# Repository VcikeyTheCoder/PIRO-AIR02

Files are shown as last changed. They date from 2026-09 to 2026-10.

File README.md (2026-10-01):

# PIRO-AIR

**A high-flow, load-cell-probing toolhead for printed-gantry printers, built to perform without a big price tag.**

 

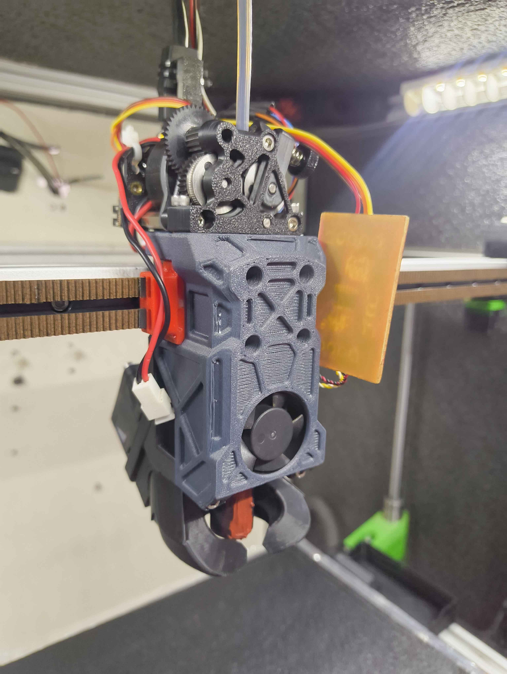
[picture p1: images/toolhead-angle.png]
PIRO-AIR on the printer


PIRO-AIR is a toolhead designed around components that actually make sense together. Printed-gantry machines are usually paired with whatever toolhead is on hand, and that is often where performance gets left behind. This design picks a Sherpa-pattern extruder, a K2 Plus hotend with its load cell, and a 4028 part-cooling fan, then arranges them so the center of mass sits between the linear rail blocks.

https://github.com/user-attachments/assets/fda07650-8147-4dfd-afff-dfcc1e427e6a

**Status: complete and open for beta testing.** There is no assembly guide or BOM yet, so you will work from the CAD for now (see [Assembly](#assembly)). Feedback is welcome, especially from anyone running a similar printed-gantry setup.

---

## Highlights

- **High flow:** the K2 Plus hotend sustains **32 mm³/s** with normal filament, and has run **PC-CF at up to 350 °C for 24+ hours**.
- **Fast, precise probing:** load-cell probing at **5 mm/s** with **1.4 µm** standard deviation (down from 4.5 µm at 2 mm/s). See [Probing](#probing).
- **Clean input shaper results:** a single dominant resonance peak on both axes, MZV recommended, under 1 % residual vibration. See [Input shaper](#input-shaper).
- **Cooling ducts designed for a 4028 fan:** low back pressure and a direct flow path. In testing you do not need more than about 50–60 % fan speed, even for a speed benchy.
- **Balanced mass:** the extruder motor sits slightly behind the hotend and mounts directly on the linear rail block, keeping a direct-drive filament path.
- **No supports needed** for any printed part.
- **Estimated total cost: about USD 100–150.**

---

## Gallery

| | |
|---|---|
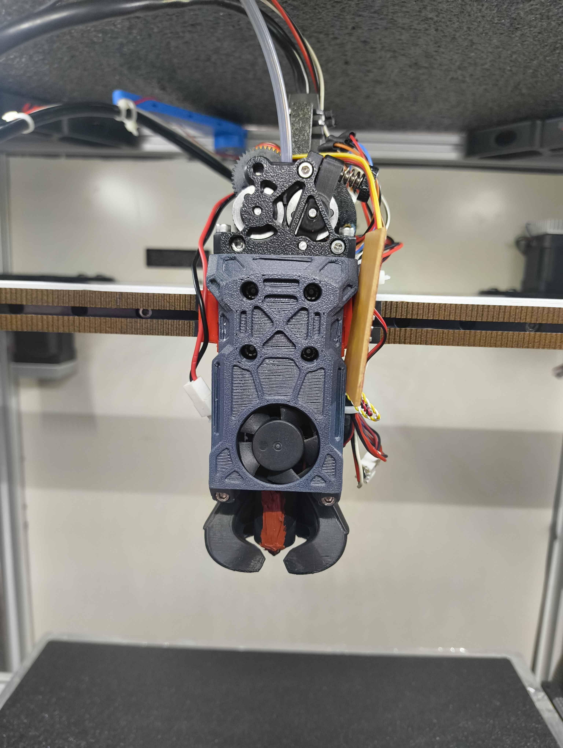
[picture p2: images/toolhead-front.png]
Front view
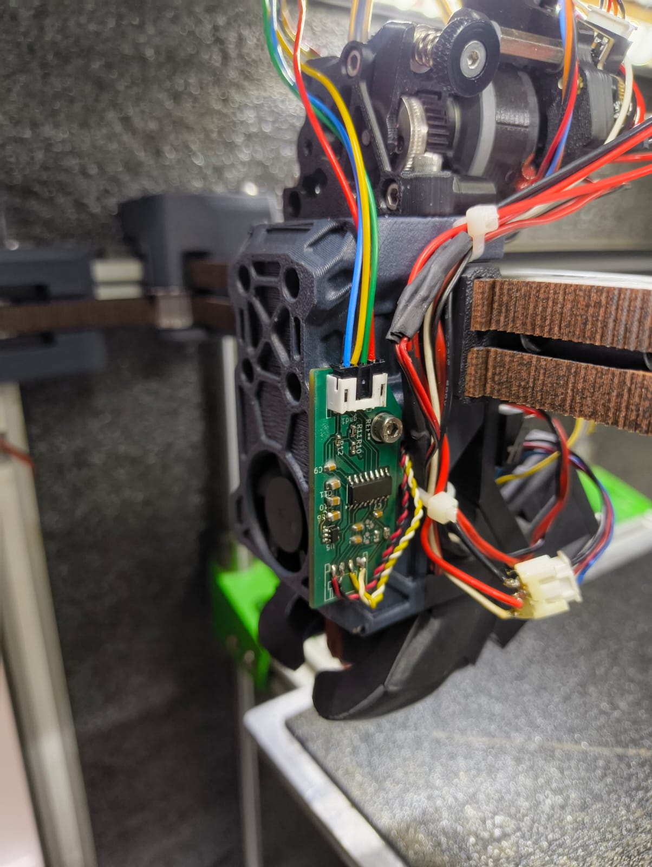
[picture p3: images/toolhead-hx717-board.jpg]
Load cell amplifier board mounted
|  |  |
| Front view | HX717 load cell amplifier board mounted on the side |
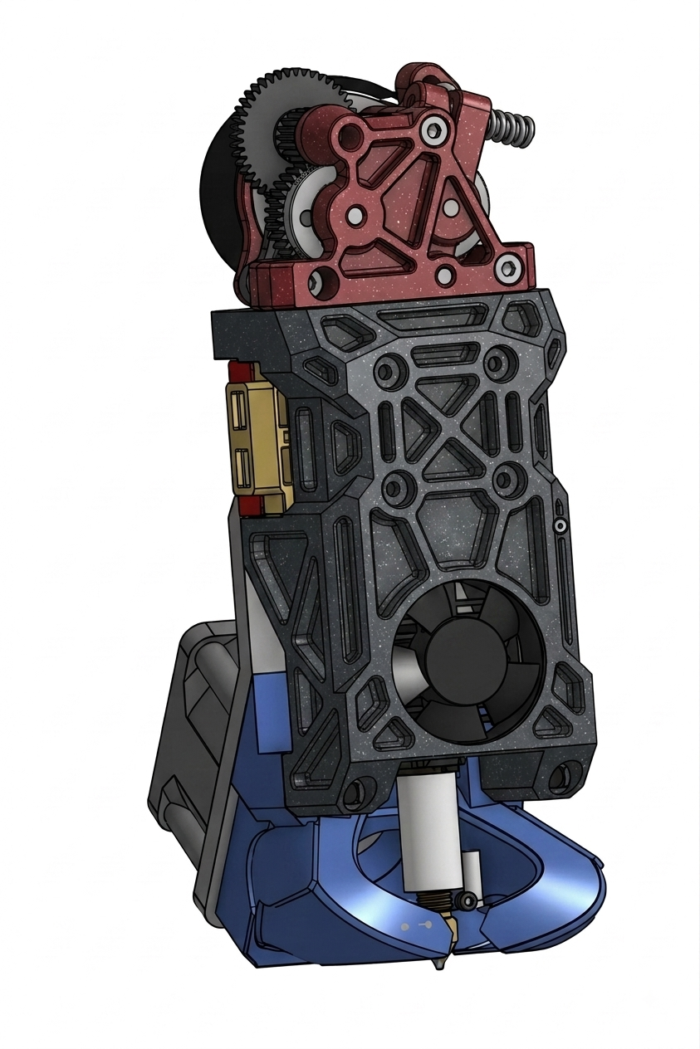
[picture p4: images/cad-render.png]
CAD render
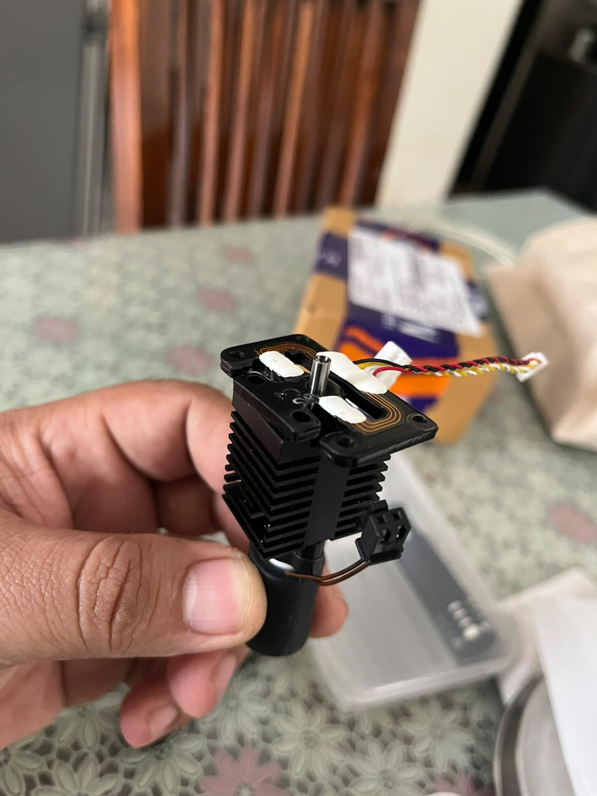
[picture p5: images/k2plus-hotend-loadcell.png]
K2 Plus hotend and load cell
|  |  |
| CAD render | K2 Plus hotend and load cell |
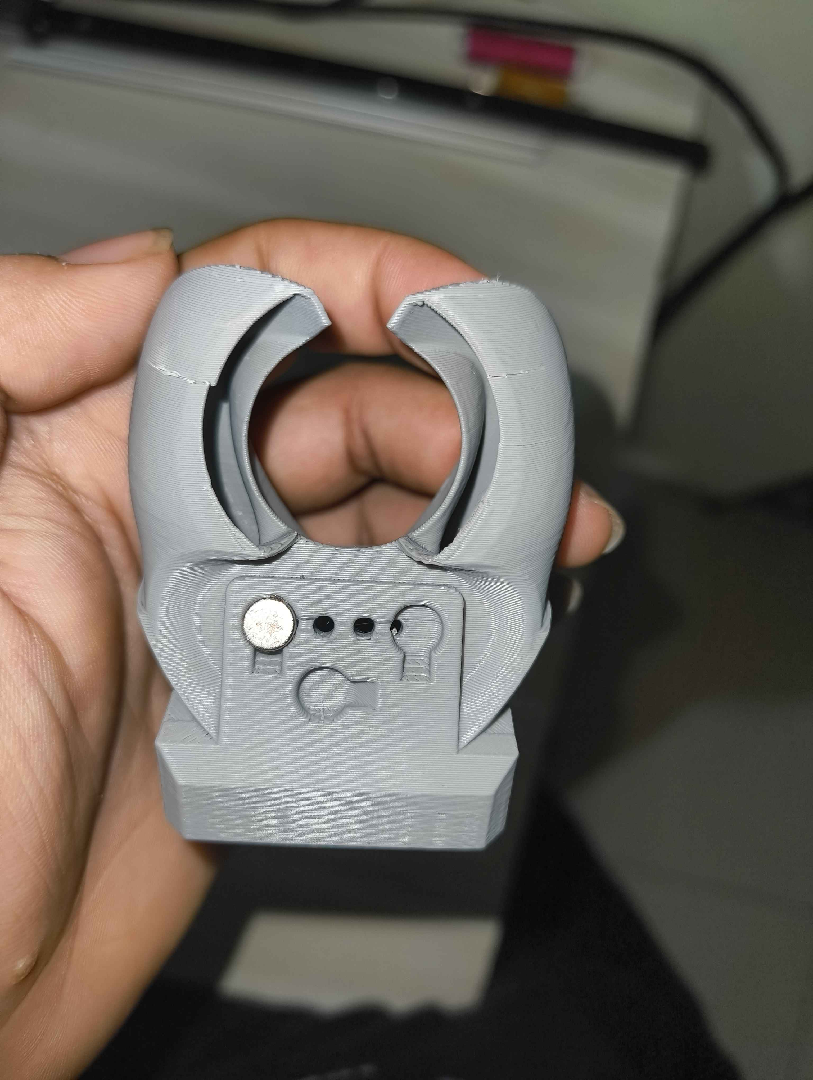
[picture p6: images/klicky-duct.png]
Klicky duct
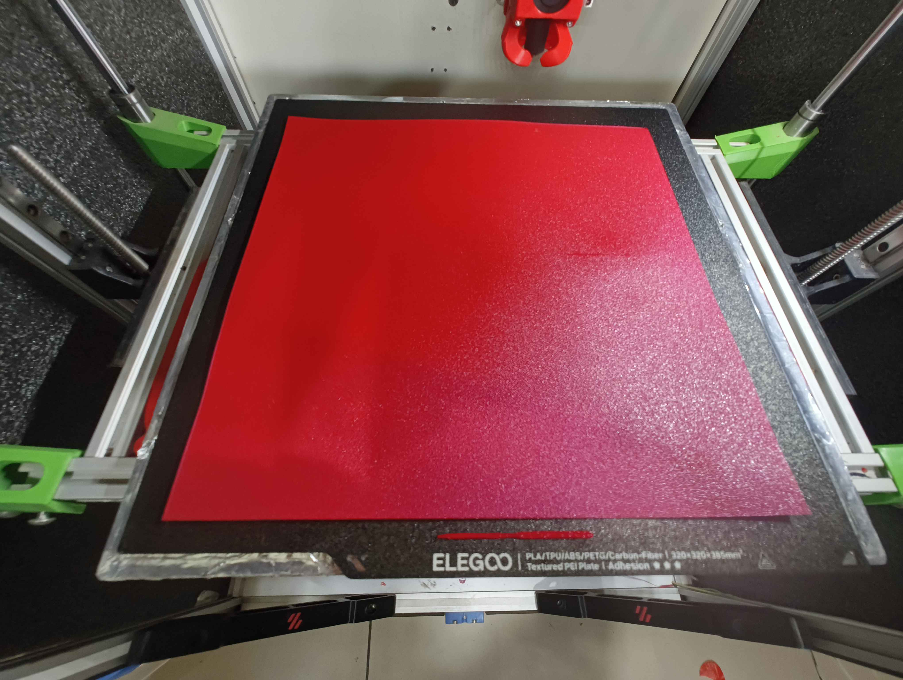
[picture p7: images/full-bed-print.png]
Full-bed print
|  |  |
| Klicky probe duct variant (magnet mount) | Full-bed print |

<!-- TODO: confirm whether the tan board in toolhead-front.png / toolhead-angle.png is an earlier iteration of the amplifier board mount, and label photos by iteration if they differ. -->

---

## Supported hardware

| Component | Supported now | Planned |
|---|---|---|
| **Hotend** | Creality K2 Plus (original recommended; OEM versions also work and cut cost) | |
| **Extruder** | Any Sherpa Mini-pattern extruder. Main target and COM-optimized: [ProtoXtruder](https://github.com/nhchiu/VoronMods/tree/main/Extruders/ProtoXtruder) | |
| **Probe** | K2 Plus load cell, Klicky probe | Eddy probes: Beacon, Cartographer |
| **Load cell amplifier** | HX717 board (any amplifier supported by Klipper works) | |
| **Part cooling fan** | 4028 | |
| **Hotend cooling fan** | 3010 | |
| **Rail** | MGN12H | |
| **Carriage** | Xol carriage clips | |
| **Printer** | Any printer with the X rail at the front | |

The toolhead has a mounting hole for the load cell amplifier PCB.

---

## Performance

### Hotend

The K2 Plus hotend is a good budget option. With a good 3010 fan and a closed chamber, no heat creep has been seen when printing PLA.

| Test | Result |
|---|---|
| Volumetric flow (OEM hotend, regular ABS and normal filament) | 32 mm³/s, reliable |
| Maximum temperature | 350 °C, tested for 24+ hours printing PC-CF |

<!-- TODO: add nozzle size, hotend temperature and test method for the 32 mm³/s figure. -->

### Cooling

Part cooling uses a single 4028 fan (31 CFM). The ducts are designed to use the fan's full output by reducing back pressure and giving the air a direct path to the nozzle. In testing, fan speed above roughly 50–60 % was not needed, even on a speed benchy.

Hotend cooling uses a 3010 fan.

### Probing

The K2 Plus load cell is read through an HX717 amplifier. Probing speed was raised from 2.0 mm/s to 5.0 mm/s, and accuracy improved rather than degraded.

| Probe speed | Standard deviation |
|---|---|
| 2.0 mm/s (before) | 4.5 µm |
| 5.0 mm/s | 1.4 µm |

A `PROBE_ACCURACY` run at a higher speed, from the Klipper console:

```
PROBE_ACCURACY SAMPLES=10 PROBE_SPEED=10 LIFT_SPEED=2
```

| Setting / result | Value |
|---|---|
| Position | X165 Y165 |
| Samples | 10 |
| Probe speed | 10 mm/s |
| Lift speed | 2 mm/s |
| Range | 0.007187 mm |
| Average | -0.015651 mm |
| Median | -0.016308 mm |
| Standard deviation | 0.002170 mm (2.17 µm) |

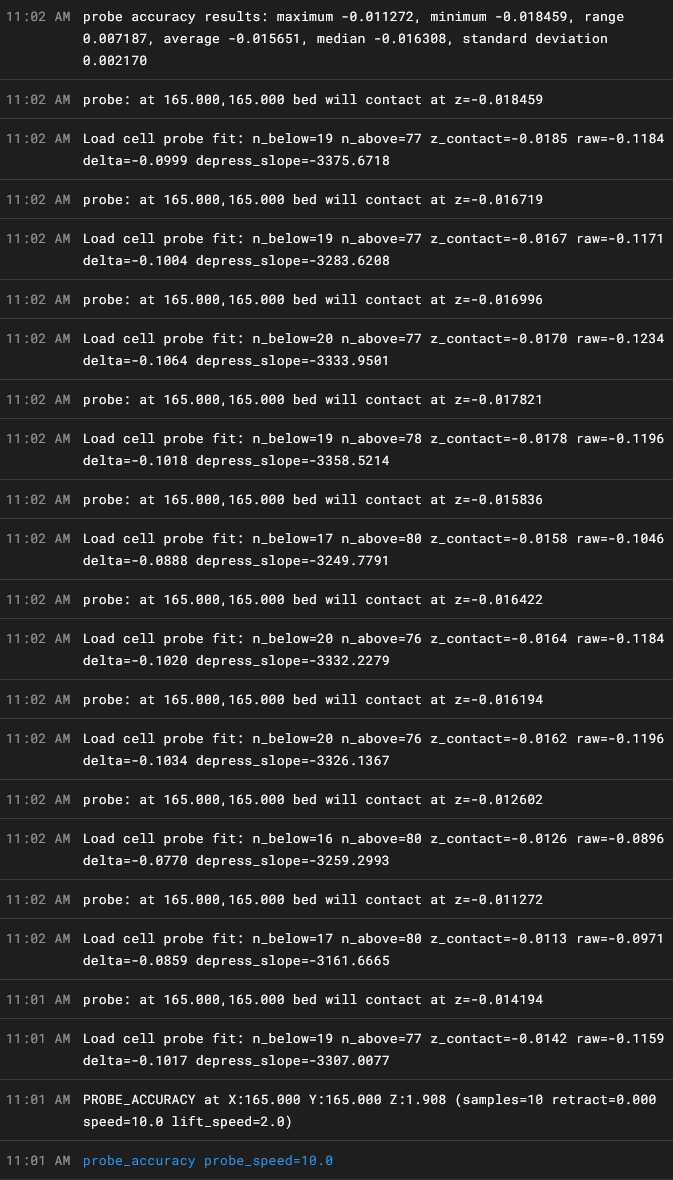
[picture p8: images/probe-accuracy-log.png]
PROBE_ACCURACY log


<!-- TODO: confirm which figures to headline. The 1.4 µm at 5 mm/s figure has no log attached; the log above is at 10 mm/s. -->

### Input shaper

Measured with Klippain Shake&Tune v6.0.0 on the author's 400 mm-class printer. Accelerations are lower on this machine because of its size, and a smaller printer should reach higher values. Results are printer-dependent.

| Axis | Resonance | Damping ratio (ζ) | Recommended shaper | Residual vibration | Smoothing | Max accel |
|---|---|---|---|---|---|---|
| X | 57.6 Hz | 0.071 | MZV @ 59.0 Hz | 0.3 % | 0.063 | 10200 mm/s² |
| Y | 40.5 Hz | 0.055 | MZV @ 40.4 Hz | 0.7 % | 0.126 | 4770 mm/s² |

Both axes show one dominant peak and a clean spectrogram. The X axis has a minor second peak at 95 Hz.

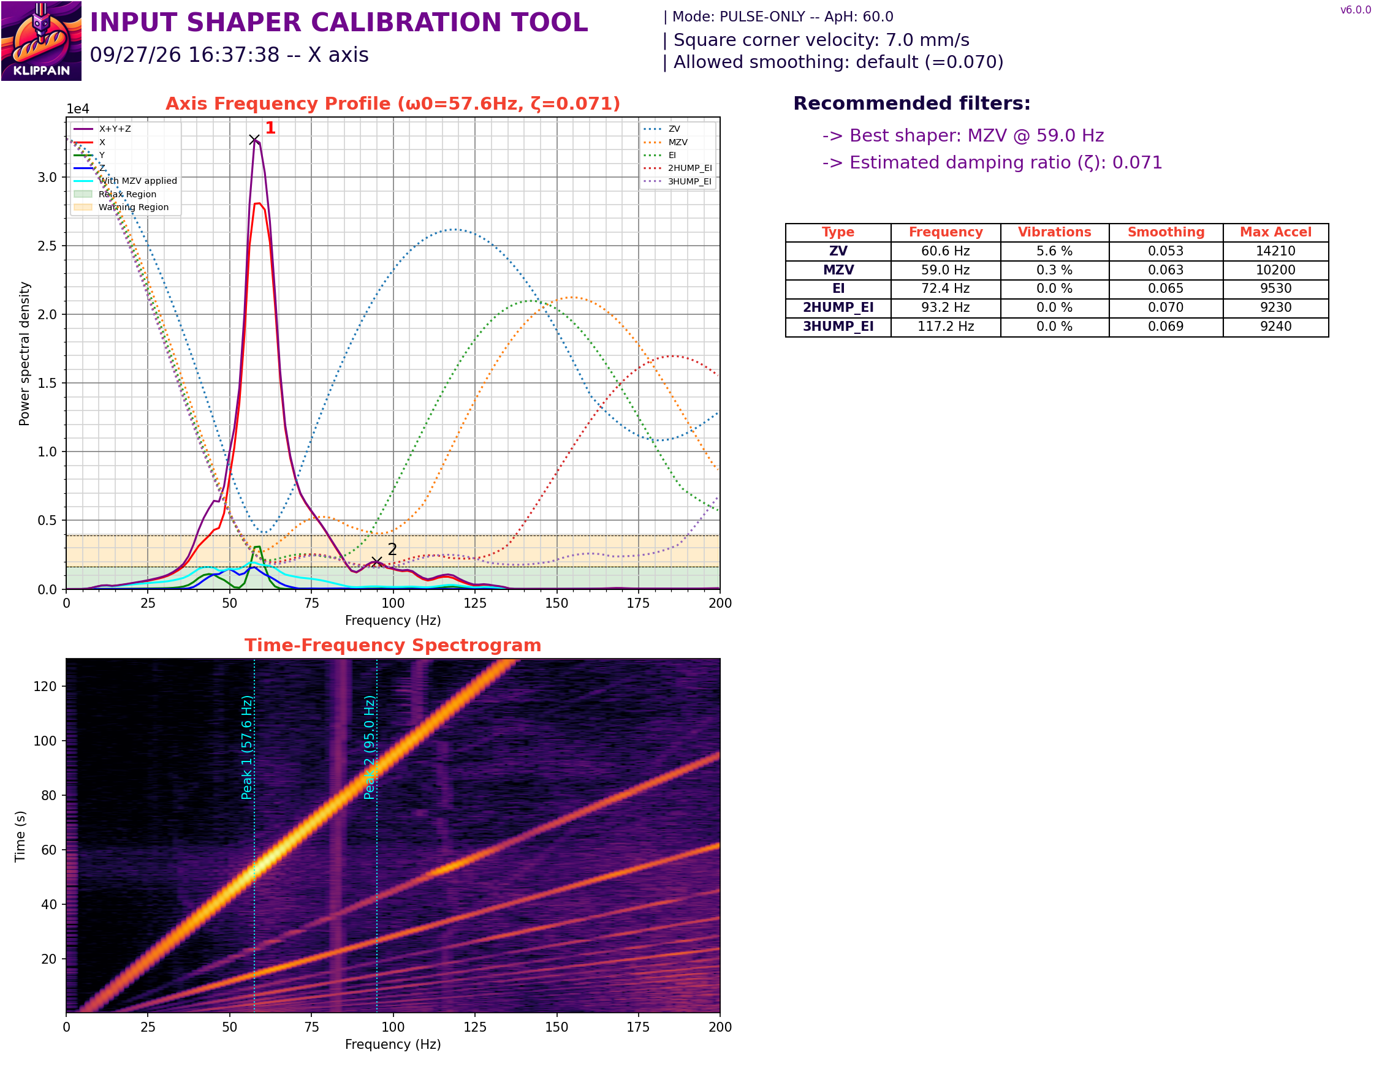
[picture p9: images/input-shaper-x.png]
X axis input shaper

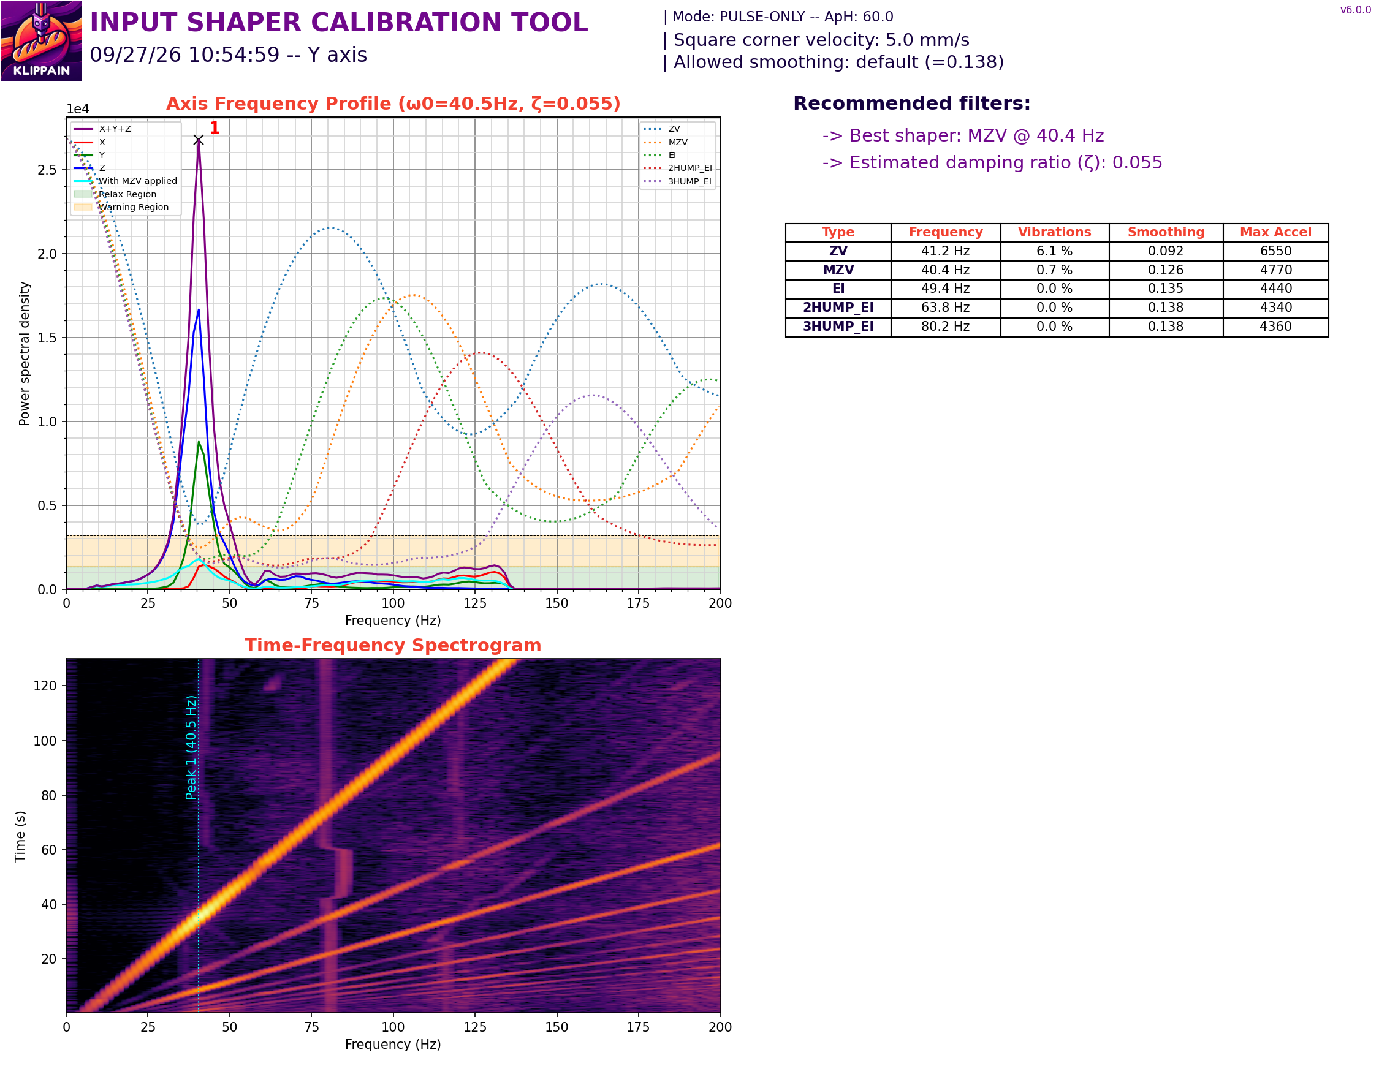
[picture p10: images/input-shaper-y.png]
Y axis input shaper


### Center of mass

The components are aligned so that the center of mass sits between the linear rail balls and blocks. The toolhead is balanced before the rest of the layout is locked in. The extruder motor sits behind the hotend and mounts directly on the rail block.

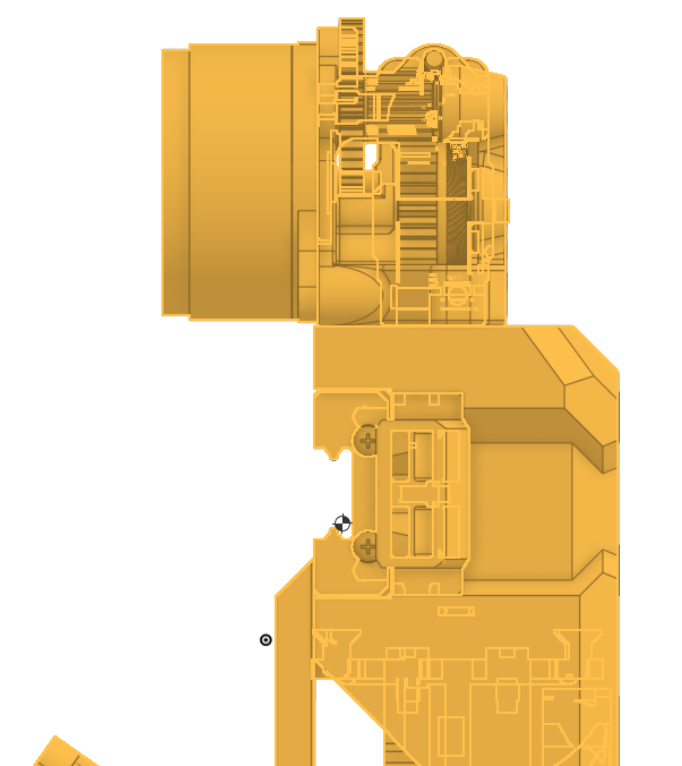
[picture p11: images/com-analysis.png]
Center of mass analysis


The center of mass analysis is optimized for the ProtoXtruder. Other Sherpa-pattern extruders fit the mount but will shift the balance.

---

## Printing the parts

| Setting | Value |
|---|---|
| Material | ABS or better (ASA, PC, and so on) |
| Nozzle | 0.4 mm or 0.6 mm |
| Walls | 5 |
| Infill | 20 % |
| Supports | None required |

<!-- TODO: add layer height, part orientation, and a file list with one row per printed part and its quantity. -->

---

## Assembly

There is currently no assembly guide or BOM. Use the CAD files in `CAD/` as the reference for now. A BOM and step-by-step guide are on the roadmap.

<!-- TODO: link CAD, STL and STEP folders once uploaded. -->

---

## Electronics and Klipper

- Load cell amplifier: HX717 board, mounted on the toolhead's PCB mounting hole. Any amplifier supported by Klipper can be used.
- Probes: K2 Plus load cell, or Klicky using the magnet-mount duct variant.

<!-- TODO: add wiring table (fan voltages, HX717 connections, probe pins) and a link to a Klipper config file with the extruder, hotend, load cell probe and fan sections. -->

---

## Roadmap

- Eddy probe support (Beacon, Cartographer)
- BOM and assembly guide
- Z thermal adjust with the load cell: Klipper's `z_thermal_adjust` currently does not work because the load cell is used for Z homing, and setting Z0 with it does not register as a switch trigger the way the module expects.

---

## Beta testing

This build is ready for beta testers. Please open an issue with:

- Your printer and gantry type
- Rail size and carriage
- Extruder and hotend used
- Photos of the fit, plus any print quality or probing results

---

## Credits

- **[Xol Toolhead](https://github.com/Armchair-Engineering/Xol-Toolhead)** by Armchair Engineering: the carriage clips used for mounting.
- **[ProtoXtruder](https://github.com/nhchiu/VoronMods/tree/main/Extruders/ProtoXtruder)** by nhchiu: the primary extruder this toolhead is designed around.
- **[Sherpa Mini](https://github.com/Annex-Engineering/Sherpa_Mini-Extruder)** by Annex Engineering: the mounting pattern.
- **[Orion Hex Drive](https://github.com/bythorsthunder/Orion-Hex-Drive)** by bythorsthunder: the duct design.
- **Creality**: K2 Plus hotend and load cell.
- **Klippain Shake&Tune**: input shaper analysis.

<!-- TODO: add any other designs, fans or components you want to credit. -->

Designed by [your name / handle].

---

## License

Licensed under the [GNU General Public License v3.0](LICENSE).

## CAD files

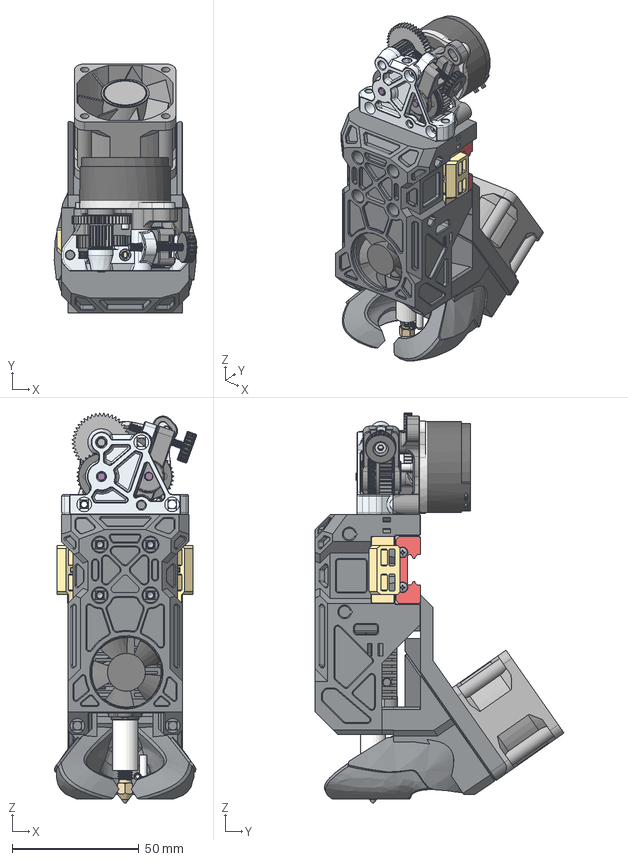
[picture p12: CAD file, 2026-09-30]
CAD/PIRO-AIR02.step
56.4 x 98.4 x 154.1 mm

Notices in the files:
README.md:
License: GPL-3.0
